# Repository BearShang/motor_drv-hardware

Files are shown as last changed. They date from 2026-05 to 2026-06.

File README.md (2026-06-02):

# 变更记录

- 取消反向二极管和栅极驱动电阻。
- 电源多了一路 LDO，直接产生 12V 电压。
- 减少了 GNDP 端大电容，只保留 104 电容。
- 取消了单片机到驱动的电阻，布局再紧凑一点。

# 概述
- 泛用低压三相电机驱动器，无感BLDC，适用于无人机ESC，RC小车驱动等。
- 上升沿10ns，极小的米勒平台。
- AT32M412KBU7-4 (Cortex-M4F)是一颗180MHz时脉带有浮点运算器的微控制器，双ADC转换器、 2个比较、4个运放，几乎不需要外设。
- 适合4s~6s电池。
- MCU的ADC(CMP INP)引脚连接端电压检测，CMP INM连接虚拟中性点，通过比较器检测反向电动势的零交越点。
- 1个直流地母线电流检测电阻，搭配MCU内建OPA可实现单电阻电流电测。
- MCU内建的OPA放大母线电流信号，可通过配置，直连内建的CMP，构成过流保护单元，过流点可由DAC配置。
- 支持雅特丽原厂上位机控制、单向DSHOT600、双向BDSHOT600。
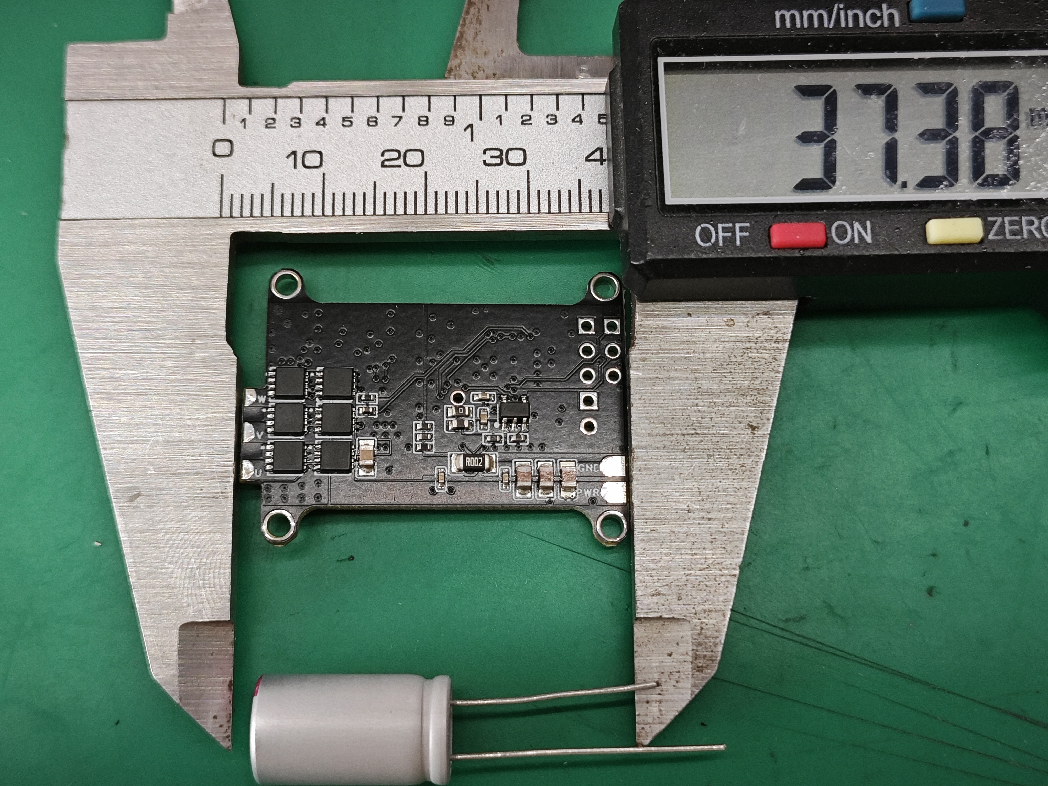
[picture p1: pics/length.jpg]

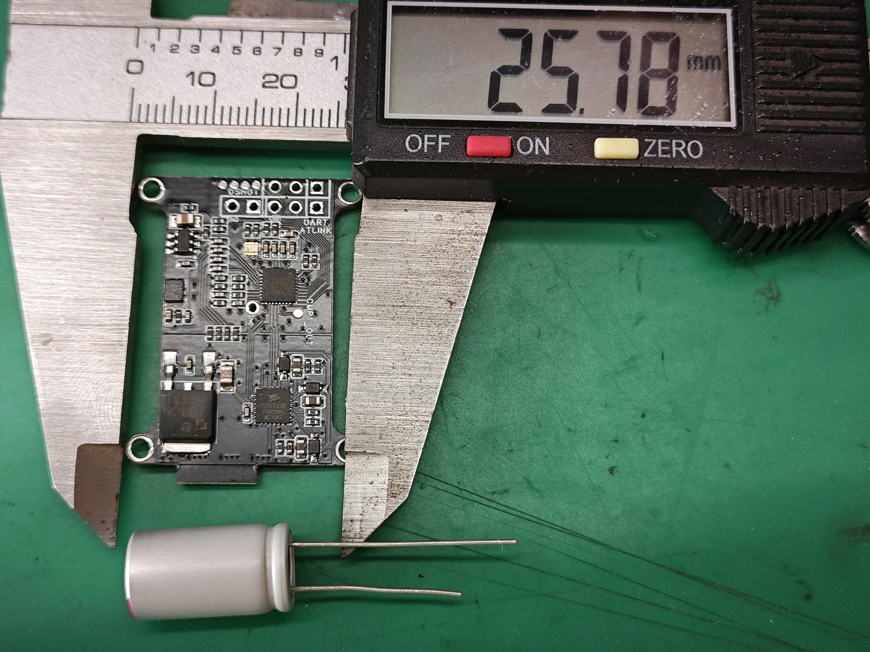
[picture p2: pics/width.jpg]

# 原理图预览

## PWR
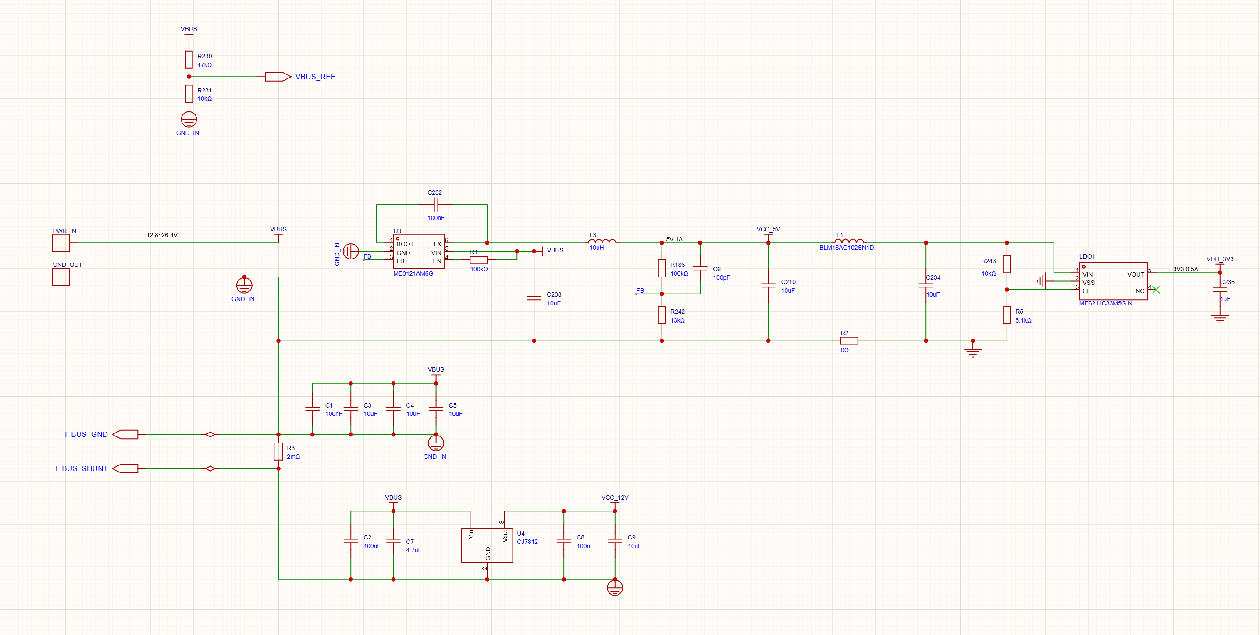
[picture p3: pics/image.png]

## MCU
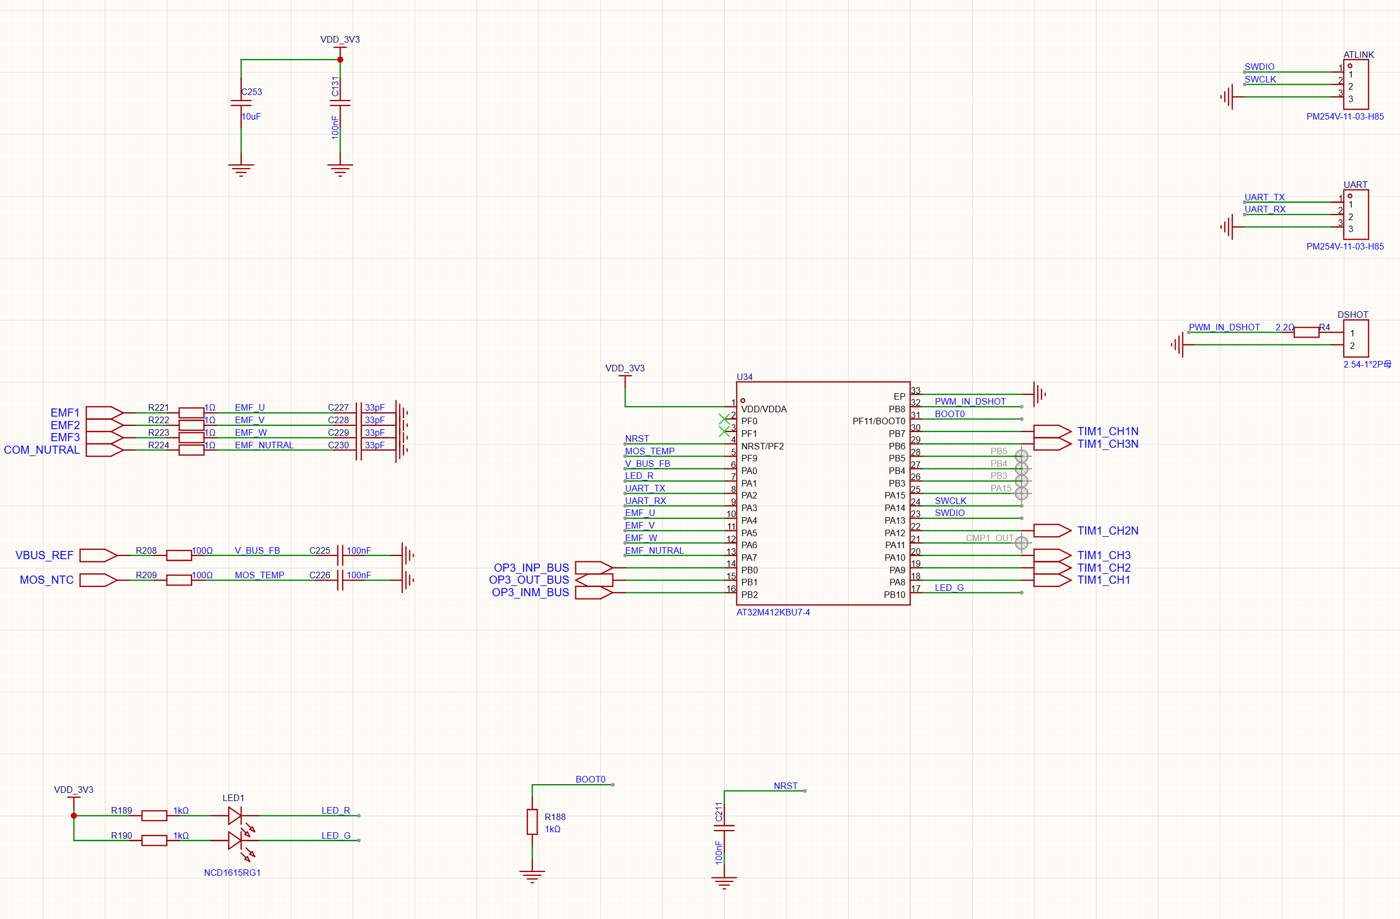
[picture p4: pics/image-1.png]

## Driver
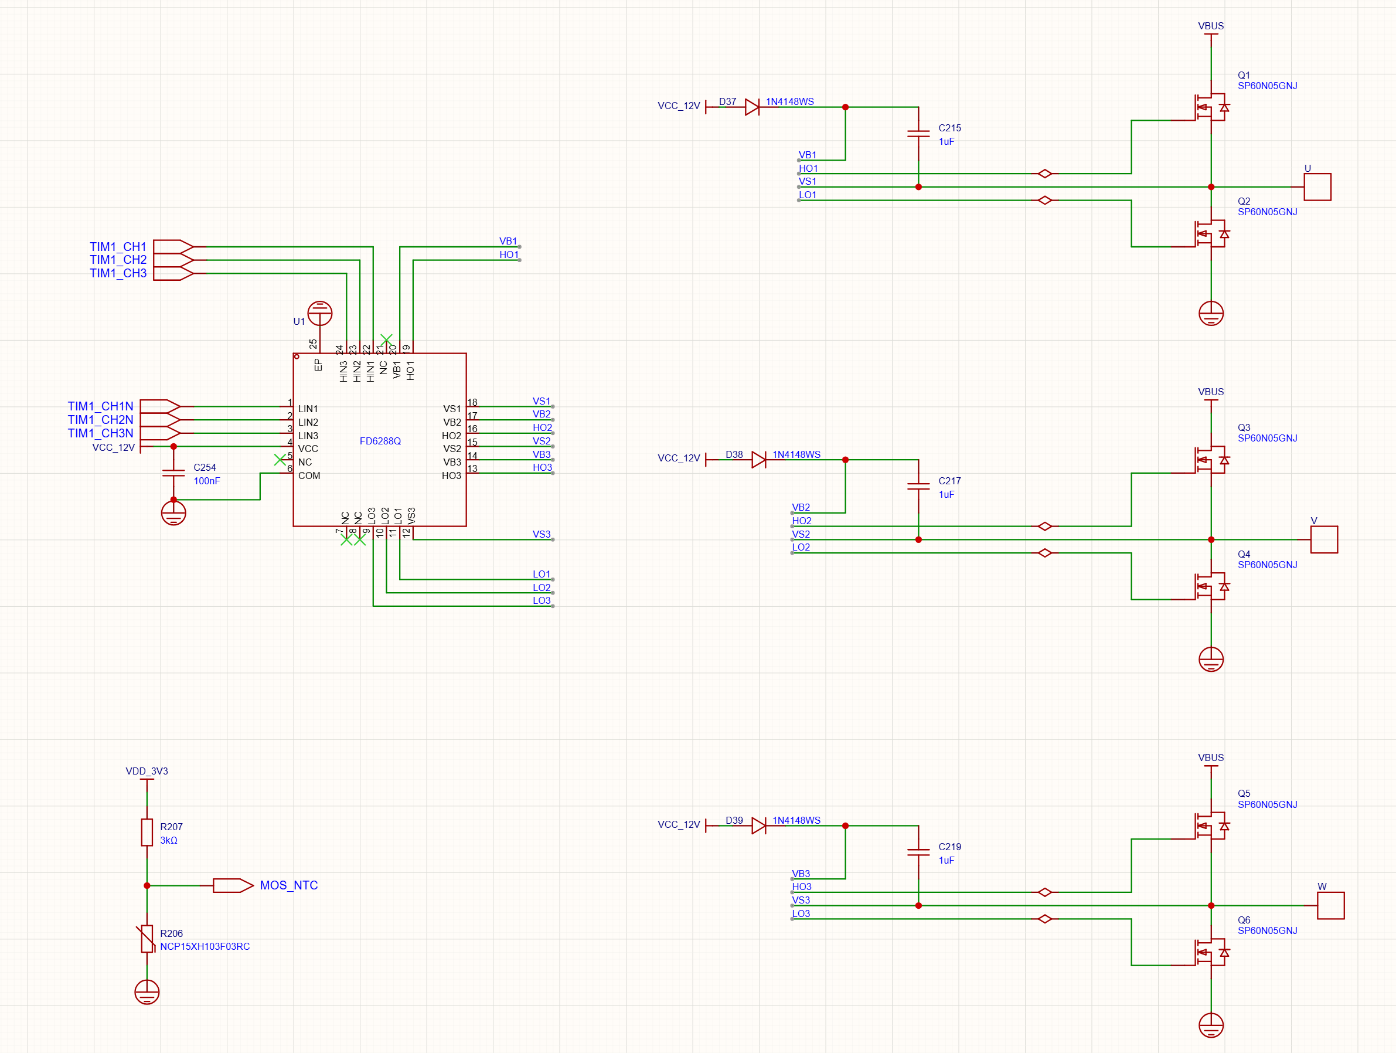
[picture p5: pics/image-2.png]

## Sensing
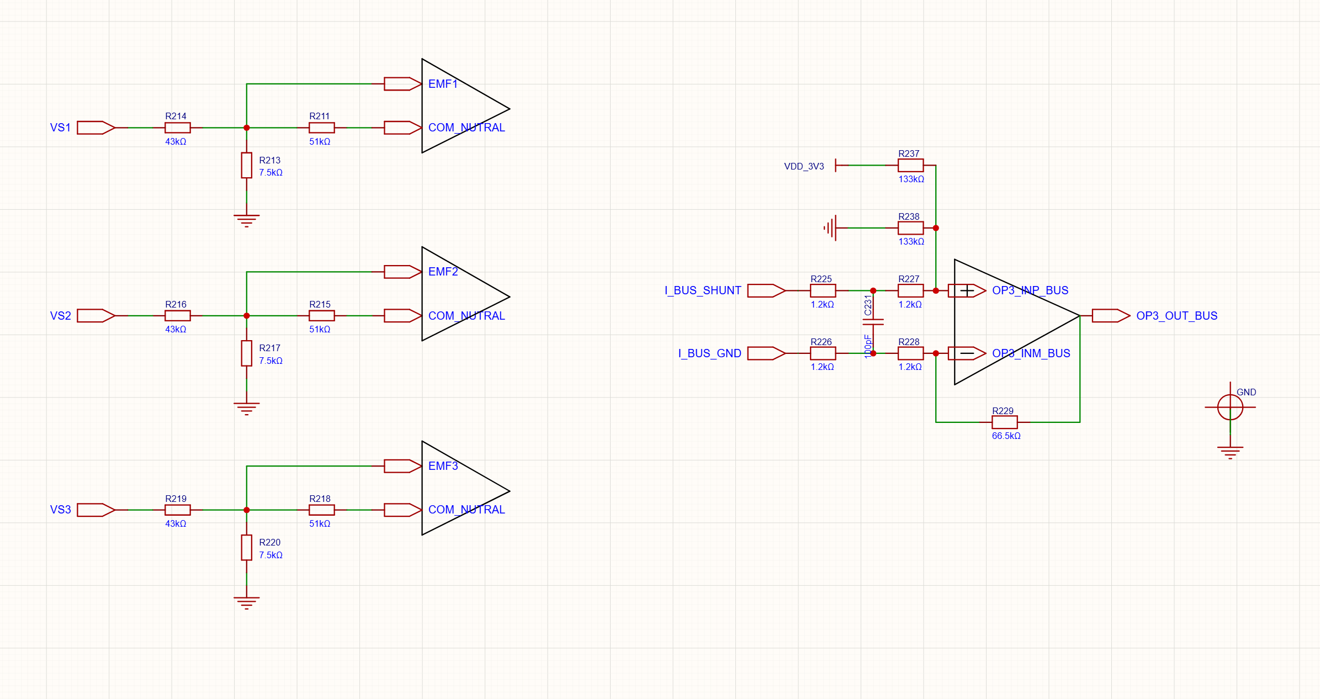
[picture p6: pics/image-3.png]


# 感谢
特别感谢雅特丽原厂工程师们的支持！！

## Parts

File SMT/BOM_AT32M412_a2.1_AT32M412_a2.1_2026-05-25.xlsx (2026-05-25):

No. | Quantity | Comment | Designator | Footprint | Value | Manufacturer Part | Manufacturer | Supplier Part | Supplier
1 | 2 | PM254V-11-03-H85 | ATLINK,UART | HDR-TH_3P-P2.54-V-F |  | PM254V-11-03-H85 | XFCN(兴飞) | C541850 | LCSC
2 | 8 | 100nF | C1,C2,C8,C131,C211,C225,C226,C232 | C0402 | 100nF | CL05B104KO5NNNC | SAMSUNG(三星) | C1525 | LCSC
3 | 4 | 10uF | C3,C4,C5,C9 | C0805 | 10uF | CL21A106KBYQNNE | SAMSUNG(三星) | C2932476 | LCSC
4 | 1 | 100pF | C6 | C0402 | 100pF | CL05C101JB5NNNC | SAMSUNG(三星) | C26409 | LCSC
5 | 1 | 4.7uF | C7 | C0805 | 4.7uF | CL21A475KBQNNNE | SAMSUNG(三星) | C98192 | LCSC
6 | 1 | 10uF | C208 | C0805 | 10uF | CL21A106KAYNNNE | SAMSUNG(三星) | C15850 | LCSC
7 | 3 | 10uF | C210,C234,C253 | C0402 | 10uF | CL05A106MQ5NUNC | SAMSUNG(三星) | C15525 | LCSC
8 | 3 | 1uF | C215,C217,C219 | C0603 | 1uF | CC0603KRX7R9BB105 | YAGEO(国巨) | C559769 | LCSC
9 | 4 | 33pF | C227,C228,C229,C230 | C0402 | 33pF | 0402CG330J500NT | FH(风华) | C1562 | LCSC
10 | 1 | 100pF | C231 | C0402 | 100pF | 0402CG101J500NT | FH(风华) | C1546 | LCSC
11 | 1 | 1uF | C236 | C0402 | 1uF | CL05A105KA5NQNC | SAMSUNG(三星) | C52923 | LCSC
12 | 1 | 100nF | C254 | C0402 | 100nF | CL05B104KB54PNC | SAMSUNG(三星) | C307331 | LCSC
13 | 3 | 1N4148WS | D37,D38,D39 | SOD-323_L1.8-W1.3-LS2.5-RD |  | 1N4148WS | CJ(江苏长电/长晶) | C2128 | LCSC
14 | 1 | 2.54-1*2P母 | DSHOT | HDR-TH_2P-P2.54-V-F |  | 2.54-1*2P母 | BOOMELE(博穆精密) | C49661 | LCSC
15 | 1 | 监测孔 | GND | M3.5金属化螺丝孔
16 | 5 | PAD_35A | GND_OUT,PWR_IN,U,V,W | PAD_35A
17 | 1 | BLM18AG102SN1D | L1 | L0603 |  | BLM18AG102SN1D | muRata(村田) | C85824 | LCSC
18 | 1 | 10uH | L3 | IND-SMD_L2.5-W2.0 | 10uH | FTC252012S100MBCA | cjiang(长江微电) | C5832376 | LCSC
19 | 1 | ME6211C33M5G-N | LDO1 | SOT-23-5_L3.0-W1.7-P0.95-LS2.8-BL |  | ME6211C33M5G-N | MICRONE(南京微盟) | C82942 | LCSC
20 | 1 | NCD1615RG1 | LED1 | LED-SMD_4P-L1.6-W1.5-TL-1 |  | NCD1615RG1 | 国星光电 | C2917181 | LCSC
21 | 6 | SP60N05GNJ | Q1,Q2,Q3,Q4,Q5,Q6 | PDFN-8L_L3.3-W3.3-P0.65-BL_G120N03D3 |  | SP60N05GNJ | Siliup(矽普) | C22466768 | LCSC
22 | 2 | 100kΩ | R1,R186 | R0402 | 100kΩ | 0402WGF1003TCE | UNI-ROYAL(厚声) | C25741 | LCSC
23 | 1 | 0Ω | R2 | R0603 | 0Ω | 0603WAF0000T5E | UNI-ROYAL(厚声) | C21189 | LCSC
24 | 1 | 2mΩ | R3 | R1206 | 2mΩ | HoJLR1206-1W-2mR-1% | Milliohm(毫欧) | C2904210 | LCSC
25 | 1 | 2.2Ω | R4 | R0402 | 2.2Ω | 0402WGJ022JTCE | UNI-ROYAL(厚声) | C25158 | LCSC
26 | 1 | 5.1kΩ | R5 | R0402 | 5.1kΩ | 0402WGF5101TCE | UNI-ROYAL(厚声) | C25905 | LCSC
27 | 3 | 1kΩ | R188,R189,R190 | R0402 | 1kΩ | 0402WGF1001TCE | UNI-ROYAL(厚声) | C11702 | LCSC
28 | 1 | NCP15XH103F03RC | R206 | R0402 |  | NCP15XH103F03RC | muRata(村田) | C77131 | LCSC
29 | 1 | 3kΩ | R207 | R0402 | 3kΩ | 0402WGF3001TCE | UNI-ROYAL(厚声) | C25784 | LCSC
30 | 2 | 100Ω | R208,R209 | R0402 | 100Ω | 0402WGF1000TCE | UNI-ROYAL(厚声) | C25076 | LCSC
31 | 3 | 51kΩ | R211,R215,R218 | R0402 | 51kΩ | 0402WGF5102TCE | UNI-ROYAL(厚声) | C25794 | LCSC
32 | 3 | 7.5kΩ | R213,R217,R220 | R0402 | 7.5kΩ | 0402WGF7501TCE | UNI-ROYAL(厚声) | C25918 | LCSC
33 | 3 | 43kΩ | R214,R216,R219 | R0402 | 43kΩ | 0402WGF4302TCE | UNI-ROYAL(厚声) | C8329 | LCSC
34 | 4 | 1Ω | R221,R222,R223,R224 | R0402 | 1Ω | 0402WGF100KTCE | UNI-ROYAL(厚声) | C25086 | LCSC
35 | 4 | 1.2kΩ | R225,R226,R227,R228 | R0402 | 1.2kΩ | RT0402BRD071K2L | YAGEO(国巨) | C852606 | LCSC
36 | 1 | 66.5kΩ | R229 | R0402 | 66.5kΩ | RT0402BRD0766K5L | YAGEO(国巨) | C852884 | LCSC
37 | 1 | 47kΩ | R230 | R0402 | 47kΩ | 0402WGF4702TCE | UNI-ROYAL(厚声) | C25792 | LCSC
38 | 2 | 10kΩ | R231,R243 | R0402 | 10kΩ | 0402WGF1002TCE | UNI-ROYAL(厚声) | C25744 | LCSC
39 | 2 | 133kΩ | R237,R238 | R0402 | 133kΩ | RT0402BRD07133KL | YAGEO(国巨) | C852517 | LCSC
40 | 1 | 13kΩ | R242 | R0402 | 13kΩ | 0402WGF1302TCE | UNI-ROYAL(厚声) | C25754 | LCSC
41 | 1 | FD6288Q | U1 | QFN-24_L4.0-W4.0-P0.50-BL-EP2.6 |  | FD6288Q | Fortior Tech(峰岹) | C328453 | LCSC
42 | 1 | ME3121AM6G | U3 | SOT-23-6_L2.9-W1.6-P0.95-LS2.8-BR |  | ME3121AM6G | MICRONE(南京微盟) | C2932938 | LCSC
43 | 1 | CJ7812 | U4 | TO-252-3_L6.5-W5.8-P4.58-BL |  | CJ7812 | CJ(江苏长电/长晶) | C26184 | LCSC
44 | 1 | AT32M412KBU7-4 | U34 | WQFN-32_L4.0-W4.0-P0.40-TL-EP2.7 |  | AT32M412KBU7-4 | ARTERY(雅特力) | C42410968 | LCSC

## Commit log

2025-10-28 继续画图
2025-10-29 完成了原理图，开始layout
2025-10-31 绘制完毕
    [BOM_AT32M412_EVB_AT32M412_EVB_2025-10-30.xlsx, PickAndPlace_AT32M412_EVB_2025-10-30.xlsx]
2025-11-24 [200~1. 母线电压检测添加分压电阻✓
2025-12-15 1. 加一路ldo 2. 换MOS驱动芯片 3. 预留反向导通二极管 4. 把TMR1CH4预留出来，配套的换一些引脚 添加了TMR1CH4在PA11; TMR1CH1N换到了PB7； LED_R换到了PA1，LED_G换到了PB10； UART_TX换到了PA2，UART_RX换到了PA3。相应的从uart1换到了uart2
    [BOM_AT32M412_EVB_AT32M412_EVB_2025-10-30.xlsx, PickAndPlace_AT32M412_EVB_2025-10-30.xlsx]
2025-12-16 继续V0.3
2025-12-17 改版完成
2025-12-23 创建V0.4
2025-12-24 完成了V0.4
    [BOM_AT32M412_EVB_V0.4_AT32M412_EVB_V0.4_2025-12-24.xlsx, PickAndPlace_AT32M412_EVB_V0.4_2025-12-24.xlsx]
2026-01-24 完成了V0.5
    [BOM_AT32M412_EVB_V0.4_AT32M412_EVB_V0.4_2025-12-24.xlsx, BOM_AT32M412_EVB_V0.5_AT32M412_EVB_V0.5_2026-01-24.xlsx, PickAndPlace_AT32M412_EVB_V0.4_2025-12-24.xls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]
2026-04-13 R213,R216,R220换成7.5k;取消了外部晶振;取消了上桥臂反向二极管;更换了mos管;添加了过流保护电路，但对应引脚的代码还没改
    [BOM_AT32M412_EVB_V0.5_AT32M412_EVB_V0.5_2026-01-24.xlsx, PickAndPlace_AT32M412_EVB_V0_5_2026_01_24.xlsx]
2026-04-15 完成了最小化布局，等结构
2026-04-21 导入了新的结构
    [电调板.DXF]
2026-04-22 完成layout
    [电调板(1).dxf]
2026-04-27 继续layout
    [电调板(1).dxf, 电调板.DXF]
2026-04-28 完成了layout
2026-05-09 完成提交
    [BOM_AT32M412_a2.0_Schematic_2026-04-29.xlsx, PickAndPlace_AT32M412_a2_0_2026_04_29.xlsx]
2026-05-14 把栅极的电阻和二极管全部拔掉
2026-05-25 **取消反向二极管和栅极驱动电阻 **电源多了一路LDO直接产生12V电压 **减少了GNDP端大电容，只保留104电容 **取消了单片机到驱动的电阻，布局再紧凑一点
    [BOM_AT32M412_a2.0_Schematic_2026-04-29.xlsx, BOM_AT32M412_a2.1_AT32M412_a2.1_2026-05-25.xlsx, PickAndPlace_AT32M412_a2_0_2026_04_29.xlsx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]
2026-05-25 优化了文档排版
2026-05-25 到处PDF
2026-05-26 添加了图片展示
2026-05-26 整理的图片格式
2026-05-26 添加了感谢
2026-05-26 完善文档
2026-05-26 修改文档
2026-06-02 附了实物图
2026-06-09 列出性能调优大纲
